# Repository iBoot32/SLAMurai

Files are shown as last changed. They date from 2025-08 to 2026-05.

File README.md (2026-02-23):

SLAM Robot

# SLAMurai Autonomous Robot

This project is an open-source implementation of a SLAM (Simultaneous Localization and Mapping) robot.  
All CAD and software is contained within this repo.

---

## Requirement Check

- [x] Omnidirectional movement using 4 dual-layer omniwheels  
- [x] Report odometry accurate to 3cm at 8ft range  
  - Last test: 12/20/2025 with 0.5% error in forward odom, within 3% error for side movement when moving 8ft straight. And 3cm off-center drift when doing pure diagonal.

---

## Features

- Real-time mapping (SLAM Toolbox)  
- Autonomous navigation (Nav2)  
- High-precision stepper-based odometry  

---

# Detailed Robot Design

## Payload

- 4x NEMA 17 Stepper Motors: 0.25kg each = 1.0kg total  
- 4x 60mm Omni wheels: 0.1kg each = 0.4kg total  
- 1x 6000mAh Lipo battery: 0.55kg  
- 1x NVIDIA Jetson Xavier NX: 0.2kg  
- 1x Intel RealSense D455: 0.3kg  
- 3x Chassis plates: 0.3kg total  
- 1x RPLIDAR A1: 0.2kg  

**Total weight: 3.5kg rounded**

---

## Desired robot specs

- Speed: 0.3 m/s  
- Acceleration: 0.5 m/s²  
- Max payload: 3.5 kg  
- Wheels: 60mm (0.0297m radius) omni wheels in 90° configuration  
- Worst case surface: Concrete (Rolling resistance ~0.03)  
- Torque safety factor: 2  

---

# Selecting Motor Parameters

## Required torque

$$
F_{\text{roll}} = \mu \cdot F_{\text{normal}} = 0.03 \cdot 3.5 \text{kg} \cdot 9.81 \text{m/s}^2 = 1.03 \text{N}
$$

$$
F_{\text{accel}} = 3.5 \text{kg} \cdot 0.5 \text{m/s}^2 = 1.75 \text{N}
$$

$$
F_{\text{total}} = 1.03 \text{N} + 1.75 \text{N} = \boxed{2.78 \text{N}}
$$

$$
\tau = F_{\text{total}} \cdot r_{\text{wheel}} = 2.78 \text{N} \cdot 0.0297 \text{m} = \boxed{0.082 \text{Nm}}
$$

This gives us the total torque required for the robot to meet our acceleration target. However, we need the worst-case torque per motor. One might assume it splits evenly between two motors when moving forward/backward or left/right. But could diagonal movement need more?

<p align="center">
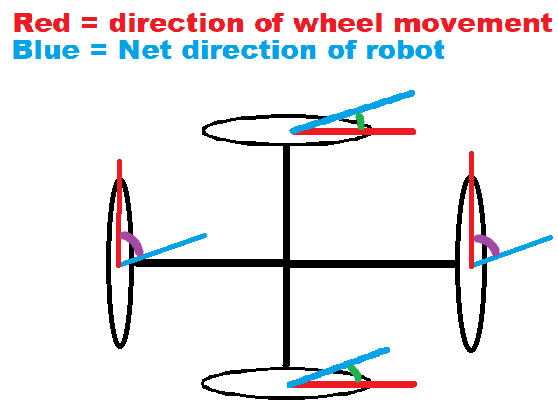
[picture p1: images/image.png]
  
</p>

If each motor provides torque $T$, the top/bottom motors contribute $2T\cos(\theta)$ and left/right motors $2T\cos(90^\circ - \theta)$, where $\theta$ is the angle of travel. We can solve for $T$ to achieve some total torque $\tau$:

$$
\tau = 2T\cos(\theta) + 2T\cos(90^\circ - \theta) \implies
T = \frac{\tau}{2(\cos(\theta) + \sin(\theta))}
$$

$T$ peaks when $\cos(\theta) + \sin(\theta)$ is minimized. We only consider $0 \leq \theta \leq 90^\circ$ since if the angle is $> 90^\circ$, we switch the direction of the top/bottom motors, yielding an angle $0 \leq \theta \leq 90^\circ$ again. Therefore the maximum of $T$ occurs when $\theta = 0^\circ$ or $90^\circ$. So yes, the worst case is moving purely along the top/bottom or left/right axes, splitting torque evenly:

$$
T = \frac{\tau}{2} = \frac{0.082 \text{Nm}}{2} = \boxed{0.041 \text{Nm}} \cdot 2_{\text{(safety factor)}} \approx \boxed{0.082 \text{Nm worst case per motor}}
$$

---

## Required RPM

$$
\text{RPM} = \frac{\text{Target velocity} \cdot 60}{2\pi r}
= \frac{0.3 \text{m/s} \cdot 60}{2\pi \cdot 0.0297 \text{m}}
\approx \boxed{96.5 \text{RPM}}
$$

---

## Motor & Driver Selection

- NEMA 17 Stepper Motors paired with an Arduino CNC Shield  
- 800 steps/rev (1/4 microstepping)  

Driver:

- A4988 or DRV8825 drivers  
- Up to 2A current capability  

Steppers provide high holding torque and precise positioning without needing external encoders. While they don't have current sensing, the open-loop nature of steppers is offset by our odometry integration.

---

# Battery Selection & Longevity

- Voltage: 12V (3S Lipo)  
- Desired Runtime: 1 hour  

## Total continuous current draw

- Motors: 0.4A each → 1.6A total  
- Jetson Xavier NX: ~15W @ 12V → 1.25A  
- RealSense D455: ~3.5W @ 5V → ~0.35A at 12V side  
- RPLIDAR A1: ~100mA  

$$
I_{\text{total}} \approx 1.6 + 1.25 + 0.35 + 0.1 = \boxed{3.3 \text{A}}
$$

To run for 1 hour:

$$
\text{Capacity} = I_{\text{total}} \cdot \text{Time}
= 3.3 \text{A} \cdot 1 \text{h}
= 3.3 \text{Ah}
= 3300 \text{mAh}
$$

Our 6000mAh battery is more than sufficient, providing a significant safety margin.

---

# Wheel Kinematics

We use inverse kinematics to command motor speeds from a target chassis twist and forward kinematics to compute odometry.

## Inverse Kinematics

$$
\begin{aligned}
\begin{bmatrix}
\omega_1\\
\omega_2\\
\omega_3\\
\omega_4
\end{bmatrix}
&=
\frac{1}{r}
\begin{bmatrix}
\sin(\gamma) & -\cos(\gamma) & -R \\
\sin\left(\frac{\pi}{2} + \gamma\right) & -\cos\left(\frac{\pi}{2} + \gamma\right) & -R \\
\sin(\pi + \gamma) & -\cos(\pi + \gamma) & -R \\
\sin\left(\frac{3\pi}{2} + \gamma\right) & -\cos\left(\frac{3\pi}{2} + \gamma\right) & -R
\end{bmatrix}
\begin{bmatrix}
v_{b,x}\\
v_{b,y}\\
\omega_{b,z}
\end{bmatrix}
\end{aligned}
$$

Where:

- $r = 0.0297\text{m}$  
- $R = 0.1325\text{m}$  
- $\gamma = 0$  

Simplified implementation (motor_controller.ino):

```
v_{Front} = -(v_y + R * omega)
v_{Left} = (v_x - R * omega)
v_{Back} = (v_y - R * omega)
v_{Right} = -(v_x + R * omega)
```

---

## Forward Kinematics

$$
\begin{aligned}
\begin{bmatrix}
v_{b,x}\\
v_{b,y}\\
\omega_{b,z}
\end{bmatrix}
&=
\begin{bmatrix}
0 & 0.5 & 0 & -0.5 \\
-0.5 & 0 & 0.5 & 0 \\
-\frac{1}{4R} & -\frac{1}{4R} & -\frac{1}{4R} & -\frac{1}{4R}
\end{bmatrix}
\begin{bmatrix}
\Delta s_1\\
\Delta s_2\\
\Delta s_3\\
\Delta s_4
\end{bmatrix}
\end{aligned}
$$

---

# Software Implementation

## Motor Control (Arduino)

The motor_controller.ino uses the MobaTools library for smooth, ramped stepper control.

- Serial Parsing: Reads $v_x$, $v_y$, $\omega$ at 40Hz  
- Speed Clamping: Ensures steps/sec never exceed STEPS_PER_SEC_MAX (2000 steps/s)  
- Odometry Integration: Calculates and broadcasts $x$, $y$, yaw over serial  

---

## Navigation Bridge (Python/ROS2)

The main.py node handles the Jetson-to-Arduino communication:

- Command Forwarding: Converts ROS Twist messages into serial strings  
- Odometry Publishing: Publishes nav_msgs/Odometry with appropriate covariances  

---

## Autonomous Navigation (Nav2)

Fully integrated with Nav2.

nav2_params.yaml limits:

```
max_vel_x: 0.25 m/s
max_vel_theta: 1.5 rad/s
```

This ensures reliable stepper performance without missing steps during complex maneuvers.

---

# License

MIT License

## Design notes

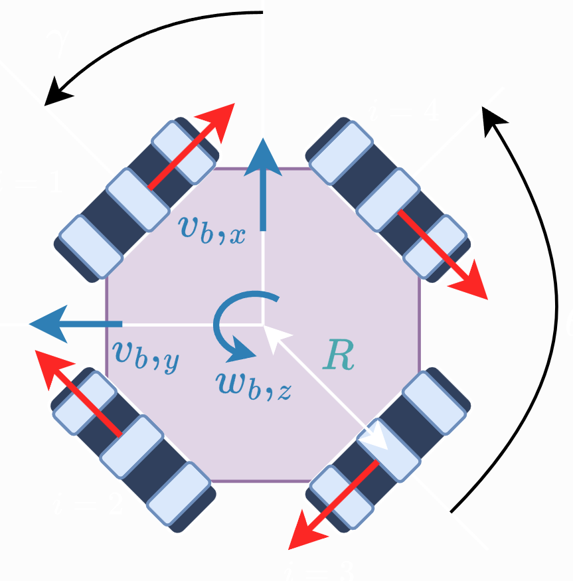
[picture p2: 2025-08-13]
images/robot_frame.PNG

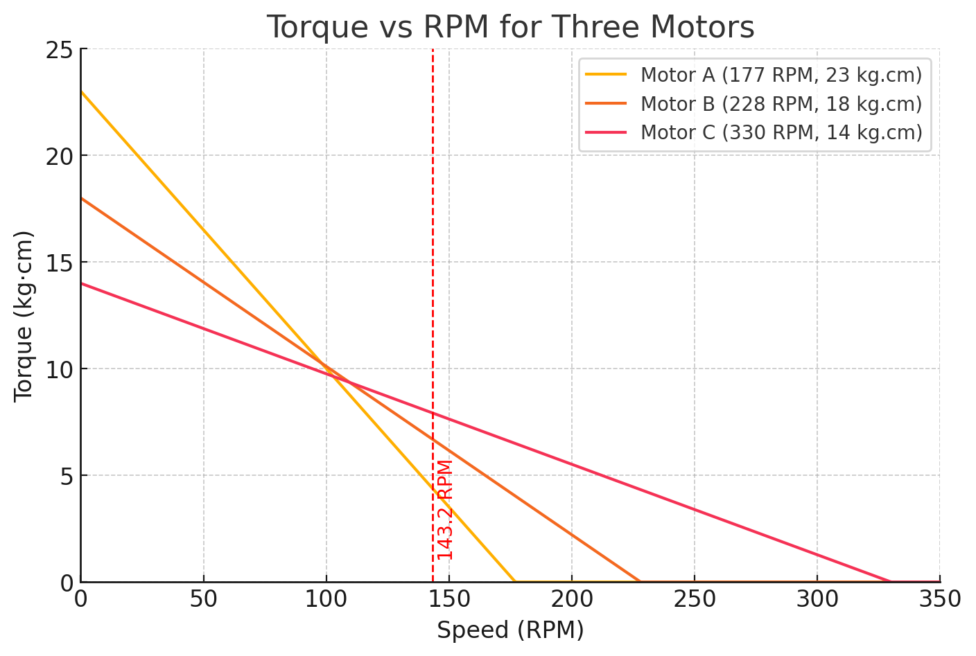
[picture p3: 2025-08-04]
images/torque_rpm.png

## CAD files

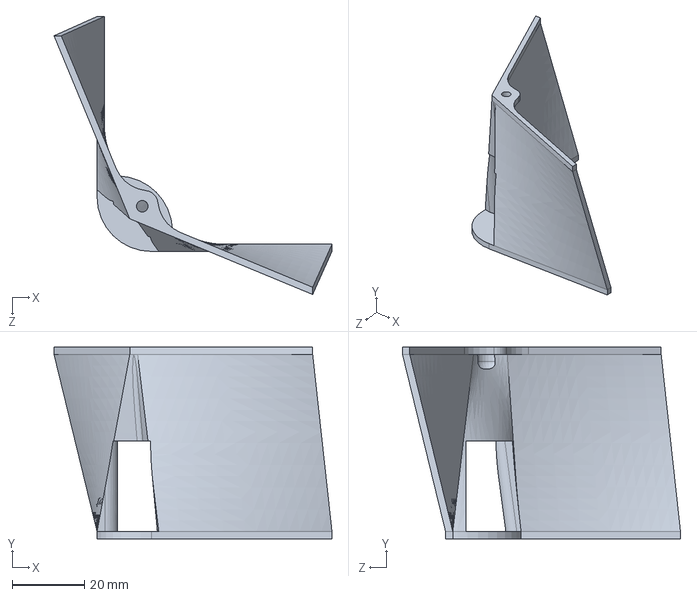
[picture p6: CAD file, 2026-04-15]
robot_cad/chassis_wall.SLDPRT
76.9 x 53.0 x 76.9 mm

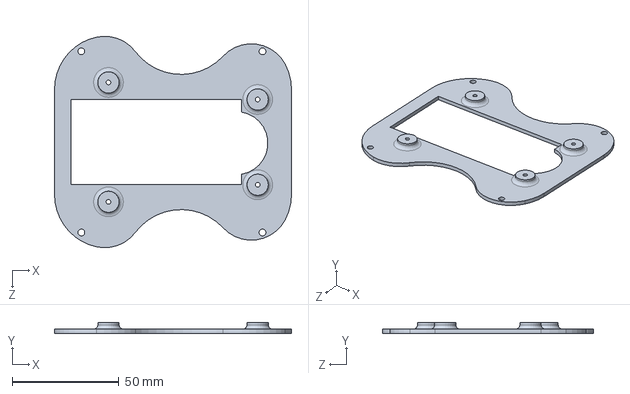
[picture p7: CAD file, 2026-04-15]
robot_cad/lidar_adapter.SLDPRT
111.2 x 5.00 x 99.2 mm

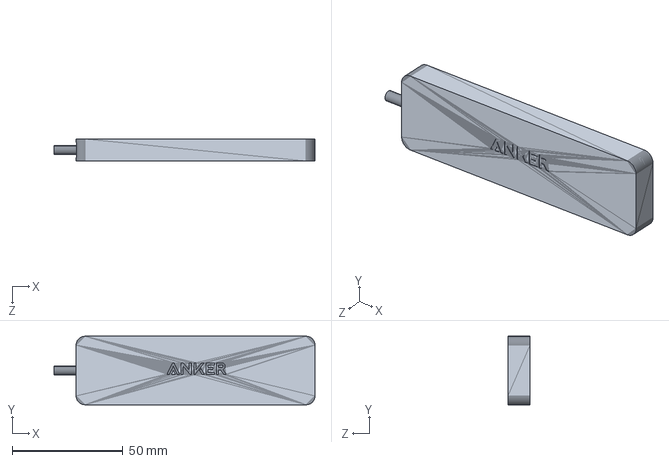
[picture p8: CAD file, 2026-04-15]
robot_cad/4-port usb 3.0 hub.SLDPRT
118.0 x 31.0 x 10.0 mm

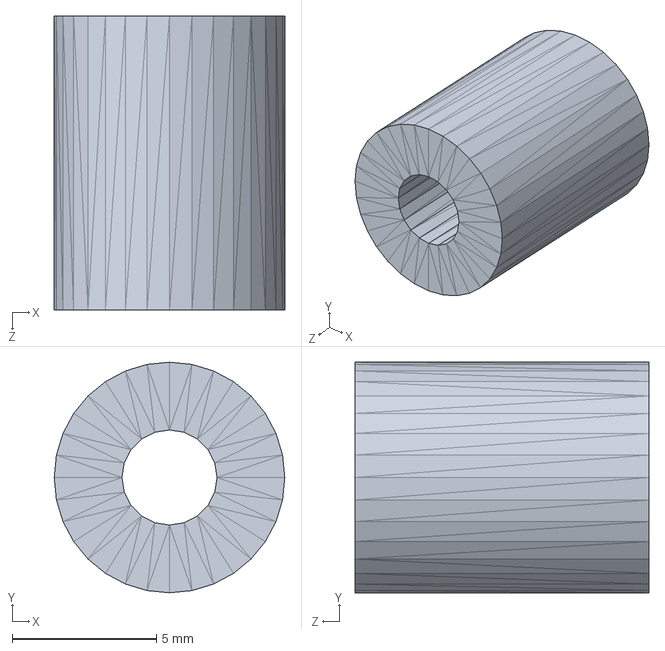
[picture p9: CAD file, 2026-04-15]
robot_cad/omni_spacer.SLDPRT
8.00 x 8.00 x 10.2 mm

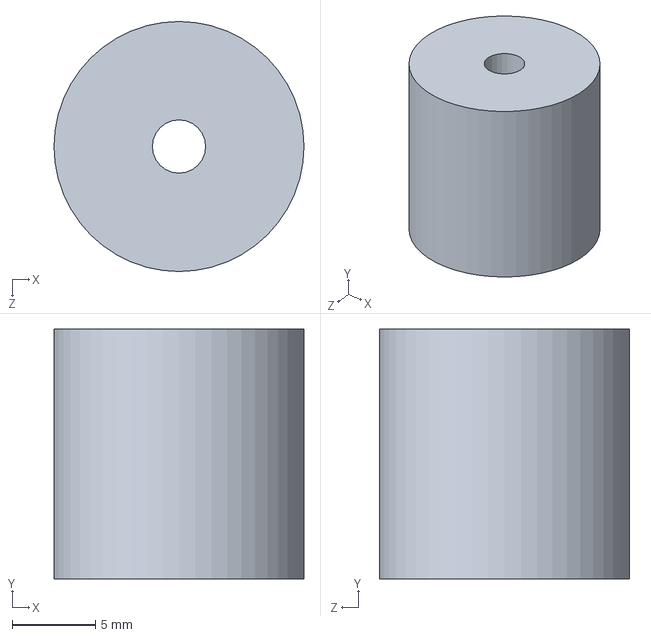
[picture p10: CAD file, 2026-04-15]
robot_cad/standoff_middle.SLDPRT
15.0 x 15.0 x 15.0 mm

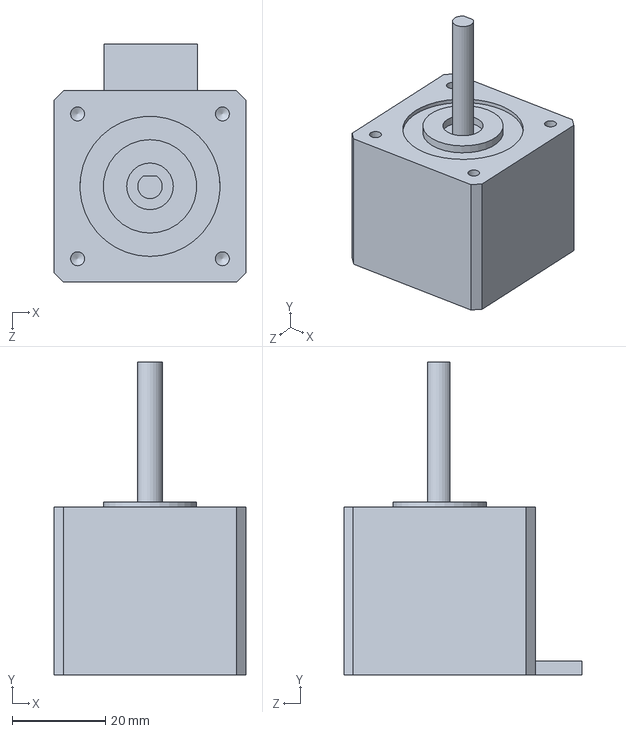
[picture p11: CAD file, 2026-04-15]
robot_cad/Stepper Motor NEMA 17 Smaller Body.SLDPRT
41.0 x 67.0 x 51.0 mm

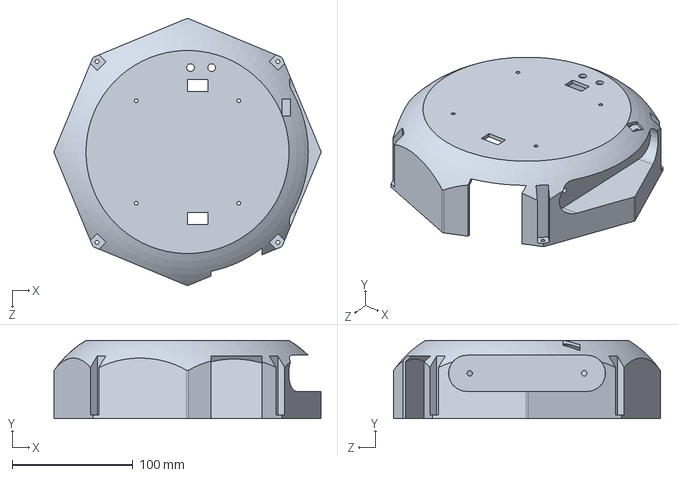
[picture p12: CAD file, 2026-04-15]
robot_cad/topv2.SLDPRT
221.5 x 65.0 x 221.5 mm

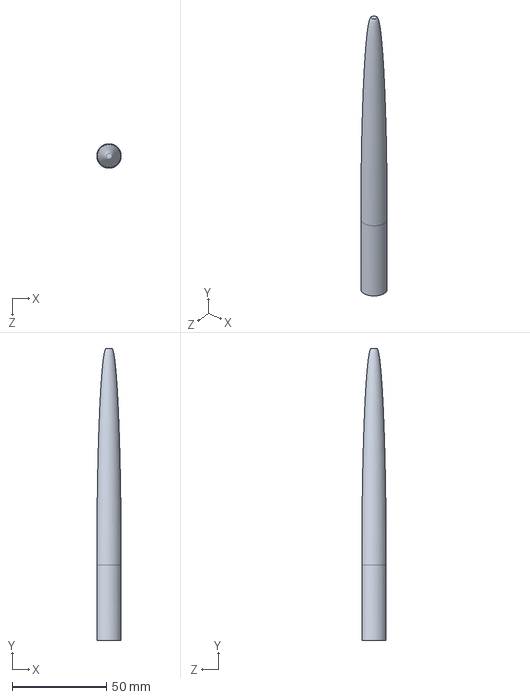
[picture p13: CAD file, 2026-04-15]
robot_cad/antenna.SLDPRT
13.0 x 155.0 x 13.0 mm

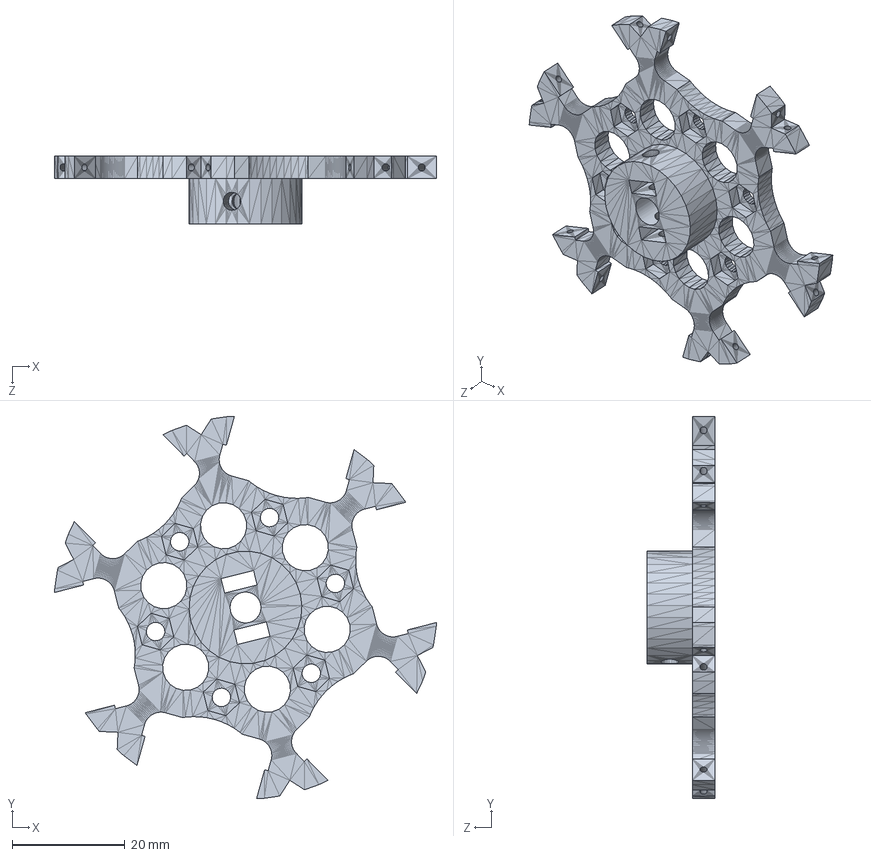
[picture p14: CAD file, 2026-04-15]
robot_cad/wheel_motor_side.SLDPRT
67.7 x 67.8 x 12.0 mm

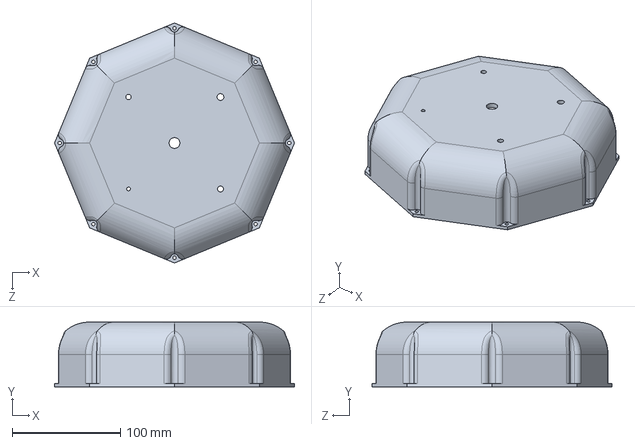
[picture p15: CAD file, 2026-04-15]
robot_cad/robot_top.SLDPRT
221.9 x 60.0 x 221.9 mm

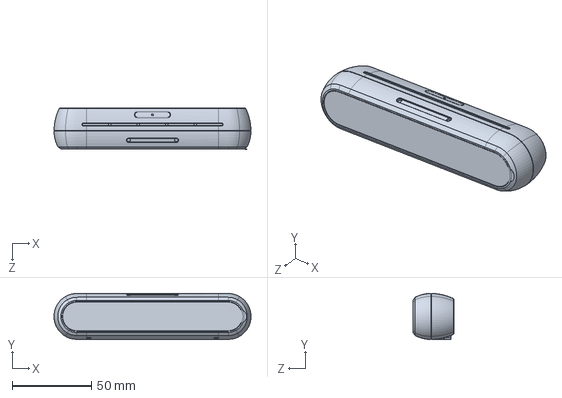
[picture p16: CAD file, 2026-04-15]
robot_cad/D455_Solid.SLDPRT
124.0 x 29.1 x 26.0 mm

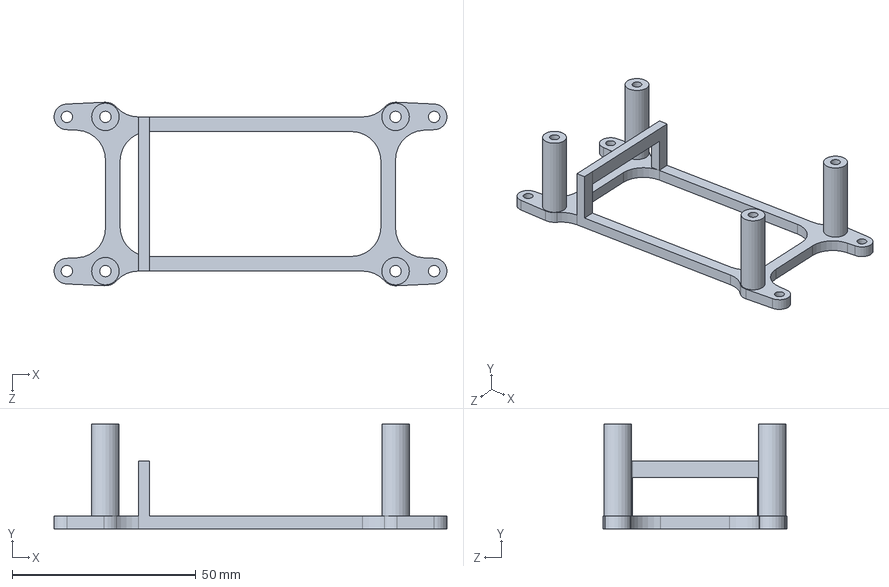
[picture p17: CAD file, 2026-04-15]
robot_cad/tx2bracked.SLDPRT
107.0 x 28.5 x 50.0 mm

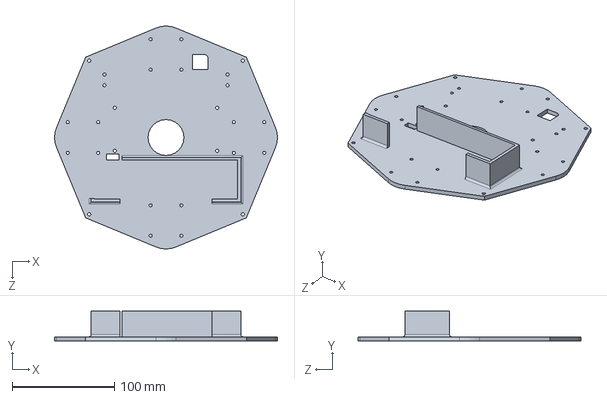
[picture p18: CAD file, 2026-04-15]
robot_cad/middle-plate.SLDPRT
217.8 x 29.0 x 217.8 mm

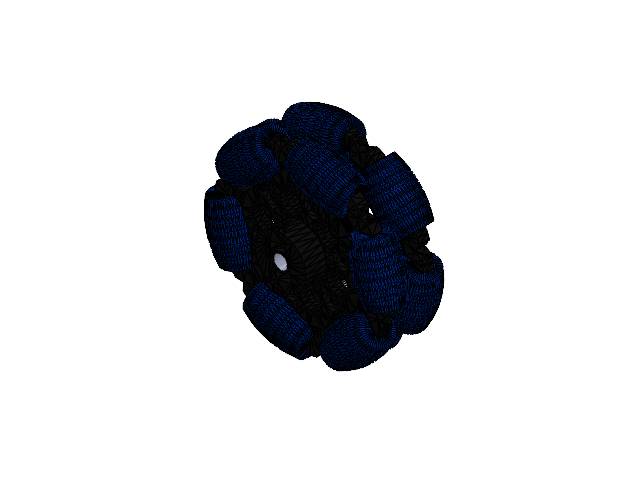
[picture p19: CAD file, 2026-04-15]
robot_cad/wheel_assem.SLDASM
wheel_motor_side
omni_roller x 12
omni_side2
omni_spacer x 3

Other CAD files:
robot_cad/Cable_3-assemv2.SLDASM
robot_cad/Cable_2-assemv2.SLDASM
robot_cad/Cable_1-assemv2.SLDASM
robot_cad/chassis_wall_no_hole.SLDPRT
robot_cad/130817_1-assemv2.SLDASM
robot_cad/ArduinoMega.SLDPRT
robot_cad/Arduino_Uno_CNC_Shield_V3.SLDPRT
robot_cad/NEMA 17 A-Body.step
robot_cad/PLASTIC HEX SPACER M3 L25.SLDPRT
robot_cad/RM_ESC_Center_Board2.stp
robot_cad/Stepper Motor NEMA 17 (1).SLDPRT
robot_cad/battery_11V_5200mAh.SLDPRT
robot_cad/chassis_layer2.SLDPRT
robot_cad/chassis_shell.SLDPRT
robot_cad/chassis_shell_final.SLDPRT
robot_cad/devkit_tx2.SLDPRT
robot_cad/layer1_shell.SLDPRT
robot_cad/middle_plate.SLDPRT
robot_cad/motor_mount.SLDPRT
robot_cad/motor_shaft.SLDPRT
robot_cad/nema_adapter.SLDPRT
robot_cad/omni_roller.SLDPRT
robot_cad/omni_side2.SLDPRT
robot_cad/standoff_53mm.SLDPRT
robot_cad/standoff_53mm.stl

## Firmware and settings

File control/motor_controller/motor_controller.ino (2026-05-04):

#include <MobaTools.h>
#include <math.h>
#define ENABLE_PIN 8
#define DISABLE_ALL_STEPPERS 0

// Robot params
#define WHEEL_RADIUS_M 0.0297
#define ROBOT_CENTER_TO_WHEEL_RADIUS 0.1325
#define STEPS_PER_REV 3200
#define STEPS_PER_SEC_MAX 5000
const float STEPS_PER_M = (float)STEPS_PER_REV / (2.0f * (float)M_PI * WHEEL_RADIUS_M);

// Kinematic Acceleration & Deceleration Limits
#define ACCEL_XY 0.40f // m/s^2
#define DECEL_XY 0.55f // m/s^2 
#define ACCEL_W  2.0f // rad/s^2
#define DECEL_W  2.0f // rad/s^2

// ------- cmd_vel parser --------
bool read_line_float(float* out) {
  static char rxbuf[64];
  static uint8_t rxlen = 0;
  while (Serial.available()) {
    char c = (char)Serial.read();
    if (c == '\n' || c == '\r') {
      if (rxlen == 0) continue;
      rxbuf[rxlen] = '\0'; rxlen = 0;
      char *p = rxbuf;
      for (int i = 0; i < 3; i++) {
        out[i] = (float)strtod(p, &p);
        if (*p == ',') p++;
      }
      return true;
    }
    if (rxlen + 1 < sizeof(rxbuf)) rxbuf[rxlen++] = c;
  }
  return false;
}

// --------- Stepper wrapper ----------
struct Stepper {
  MoToStepper drv;
  uint8_t _stepPin, _dirPin;
  Stepper(uint8_t step, uint8_t dir) : drv(STEPS_PER_REV, STEPDIR), _stepPin(step), _dirPin(dir) {}
  inline long pos() const { return drv.readSteps(); }

  void setup() { 
    drv.attach(_stepPin, _dirPin); 
    drv.setRampLen(0);
    drv.setSpeed(0);
  }

  void setLinearVelocity(float v_mps) {
    float sps = v_mps * STEPS_PER_M;
    if (fabs(sps) > STEPS_PER_SEC_MAX) sps = copysign(STEPS_PER_SEC_MAX, sps);
    if (fabs(sps) < 1e-3) {
      drv.rotate(0);
      drv.setSpeedSteps(0);
      return;
    }
    uint16_t steps10 = (uint16_t)(fabs(sps) * 10.0f);    drv.setSpeedSteps(steps10);
    if (sps == 0) {
      drv.setSpeedSteps(0);
    } else if (sps > 0) {
      drv.rotate(1);
    } else {
      drv.rotate(-1);
    }
  }
};

Stepper stepperFront(3, 6);
Stepper stepperLeft(2, 5);
Stepper stepperBack(4, 7);
Stepper stepperRight(12, 13);

void setup() {
  Serial.begin(115200);
  pinMode(ENABLE_PIN, OUTPUT);
  if (DISABLE_ALL_STEPPERS) { digitalWrite(ENABLE_PIN, HIGH); return; }
  digitalWrite(ENABLE_PIN, LOW);
  delayMicroseconds(2000);
  stepperFront.setup(); stepperLeft.setup(); stepperBack.setup(); stepperRight.setup();
}

// -------- KINEMATIC STATE --------
float target_vx = 0, target_vy = 0, target_w = 0;
float current_vx = 0, current_vy = 0, current_w = 0;

float CMD_VEL_READ_PERIOD_US = 1e6 * (1 / 40.0);
unsigned long last_cmd_vel_send_time = 0;
unsigned long last_cmd_received_time = 0;
const unsigned long CMD_TIMEOUT_US = 500000;

float ODOM_SEND_PERIOD_US = 1e6 * (1 / 40.0);
float pose_x = 0, pose_y = 0, pose_yaw = 0;
float dx_b_sum = 0, dy_b_sum = 0, dyaw_sum = 0; 
long lastFront = 0, lastLeft = 0, lastBack = 0, lastRight = 0;
unsigned long last_odom_send_time = 0;

float move_towards(float current, float target, float accel_limit, float decel_limit, float dt) {
  if (current == target) return current;
  bool accelerating = (target > 0 && current >= 0 && target > current) || (target < 0 && current <= 0 && target < current);
  float max_step = (accelerating ? accel_limit : decel_limit) * dt;
  if (current < target) {
    current += max_step;
    if (current > target) current = target;
  } else {
    current -= max_step;
    if (current < target) current = target;
  }
  return current;
}

void loop() {
  unsigned long now = micros();
  float cmd_v[3];
  if (read_line_float(cmd_v)) {
    
    last_cmd_received_time = now;
    target_vx = cmd_v[0];
    target_vy = cmd_v[1];
    target_w  = cmd_v[2];
  }

  // ---- KINEMATIC TIMING & SMOOTHING ----
  if (now - last_cmd_vel_send_time >= CMD_VEL_READ_PERIOD_US) {
    float dt_smooth = (now - last_cmd_vel_send_time) / 1000000.0f;
    last_cmd_vel_send_time = now;

    // Timeout Safety
    if (now - last_cmd_received_time > CMD_TIMEOUT_US) {
      target_vx = 0; target_vy = 0; target_w = 0;
    }

    // Apply acceleration limits
    current_vx = move_towards(current_vx, target_vx, ACCEL_XY, DECEL_XY, dt_smooth);
    current_vy = move_towards(current_vy, target_vy, ACCEL_XY, DECEL_XY, dt_smooth);
    current_w  = move_towards(current_w,  target_w,  ACCEL_W,  DECEL_W,  dt_smooth);

    float vFront = -(current_vy + ROBOT_CENTER_TO_WHEEL_RADIUS * current_w);
    float vLeft  =  (current_vx - ROBOT_CENTER_TO_WHEEL_RADIUS * current_w);
    float vBack  =  (current_vy - ROBOT_CENTER_TO_WHEEL_RADIUS * current_w);
    float vRight = -(current_vx + ROBOT_CENTER_TO_WHEEL_RADIUS * current_w);
   
    stepperFront.setLinearVelocity(vFront);
    stepperLeft.setLinearVelocity(vLeft);
    stepperBack.setLinearVelocity(vBack);
    stepperRight.setLinearVelocity(vRight);
  }

  // ---- ODOM UPDATE (Runs as fast as possible) ----
  long pFront = stepperFront.pos();
  long pLeft = stepperLeft.pos();
  long pBack = stepperBack.pos();
  long pRight = stepperRight.pos();

  long dFront = pFront - lastFront;
  long dLeft = pLeft - lastLeft;
  long dBack = pBack - lastBack;
  long dRight = pRight - lastRight;
  lastFront = pFront; lastLeft = pLeft; lastBack = pBack; lastRight = pRight;

  float sFront = (float)dFront / STEPS_PER_M;
  float sLeft = (float)dLeft / STEPS_PER_M;
  float sBack = (float)dBack / STEPS_PER_M;
  float sRight = (float)dRight / STEPS_PER_M;

  float dx_b = ( sLeft - sRight ) * 0.5f;
  float dy_b = (-sFront + sBack ) * 0.5f;
  float dyaw = -(sFront + sLeft + sBack + sRight) * (1.0f / (4.0f * ROBOT_CENTER_TO_WHEEL_RADIUS));

  dx_b_sum += dx_b;
  dy_b_sum += dy_b;
  dyaw_sum += dyaw;

  float cy = cos(pose_yaw);
  float sy = sin(pose_yaw);
  pose_x += cy * dx_b - sy * dy_b;
  pose_y += sy * dx_b + cy * dy_b;
  pose_yaw += dyaw;

  // ---- SERIAL ODOM SEND ----
  now = micros();
  if (now - last_odom_send_time >= ODOM_SEND_PERIOD_US) {
    float dt_odom = (now - last_odom_send_time) / 1000000.0f;
    last_odom_send_time = now;

    float x_mm = roundf(pose_x * 1000.0f) / 1000.0f;
    float y_mm = roundf(pose_y * 1000.0f) / 1000.0f;
    float yaw_r = roundf(pose_yaw * 1000.0f) / 1000.0f;
    float vel_x = dx_b_sum / dt_odom;
    float vel_y = dy_b_sum / dt_odom;
    float vel_w = dyaw_sum / dt_odom;

    dx_b_sum = 0; dy_b_sum = 0; dyaw_sum = 0;

    Serial.print(x_mm, 3); Serial.print(',');
    Serial.print(y_mm, 3); Serial.print(',');
    Serial.print(yaw_r, 3); Serial.print(',');
    Serial.print(vel_x, 3); Serial.print(',');
    Serial.print(vel_y, 3); Serial.print(',');
    Serial.println(vel_w, 3);
  }
}

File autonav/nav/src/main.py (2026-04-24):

#!/usr/bin/env python3
import rclpy
from rclpy.node import Node
from rclpy.qos import QoSProfile, QoSReliabilityPolicy
from nav_msgs.msg import Odometry
from geometry_msgs.msg import Twist
import serial
import time
import math


class CmdVelSerialOdom(Node):
    def __init__(self, ser, hz=50.0):
        super().__init__('cmdvel_serial_odom')
        self.ser = ser

        qos = QoSProfile(depth=10)
        qos.reliability = QoSReliabilityPolicy.BEST_EFFORT

        self.publisher = self.create_publisher(Odometry, '/odometry/raw', 10)
        self.subscriber = self.create_subscription(
            Twist, '/cmd_vel', self.cmd_vel_callback, qos)

        self.frame_id = "odom"
        self.child_frame_id = "base_link"

        # Current odom pose
        self.x = 0.0
        self.y = 0.0
        self.yaw = 0.0
        
        # Current odom velocity
        self.vx = 0.0
        self.vy = 0.0
        self.vw = 0.0

        self.create_timer(1.0 / hz, self.publish_odom)

    # Writes data via USB serial to be received by Arduino
    def cmd_vel_callback(self, msg: Twist):
        cmd = f"{msg.linear.x},{msg.linear.y},{msg.angular.z}\n"
        self.ser.write(cmd.encode())

    def publish_odom(self):
        # Read any available odom serial line from Arduino
        try:
            line = self.ser.readline().decode().strip()
            if line:
                parts = line.split(',')
                if len(parts) == 6:
                    self.x = float(parts[0])   # meters
                    self.y = float(parts[1])
                    self.yaw = float(parts[2])
                    self.vx = float(parts[3])  # meters/sec
                    self.vy = float(parts[4])
                    self.vw = float(parts[5])
        except Exception:
            pass  # ignore malformed lines

        # Convert yaw -> quaternion
        qz = math.sin(self.yaw * 0.5)
        qw = math.cos(self.yaw * 0.5)

        msg = Odometry()
        msg.header.stamp = self.get_clock().now().to_msg()
        msg.header.frame_id = self.frame_id
        msg.child_frame_id = self.child_frame_id

        # Populate Pose
        msg.pose.pose.position.x = self.x
        msg.pose.pose.position.y = self.y
        msg.pose.pose.position.z = 0.0
        msg.pose.pose.orientation.x = 0.0
        msg.pose.pose.orientation.y = 0.0
        msg.pose.pose.orientation.z = qz
        msg.pose.pose.orientation.w = qw
        
        # 5mm std in pose, 0.1deg std orientation
        msg.pose.covariance = [
            2.5e-05, 0.0,     0.0,     0.0,     0.0,     0.0,
            0.0,     2.5e-05, 0.0,     0.0,     0.0,     0.0,
            0.0,     0.0,     1.0,     0.0,     0.0,     0.0,
            0.0,     0.0,     0.0,     1.0,     0.0,     0.0,
            0.0,     0.0,     0.0,     0.0,     1.0,     0.0,
            0.0,     0.0,     0.0,     0.0,     0.0,     3.05e-06
        ]

        # Populate Twist (Velocity)
        msg.twist.twist.linear.x = self.vx
        msg.twist.twist.linear.y = self.vy
        msg.twist.twist.linear.z = 0.0
        msg.twist.twist.angular.x = 0.0
        msg.twist.twist.angular.y = 0.0
        msg.twist.twist.angular.z = self.vw
        
        # Basic twist covariance 
        msg.twist.covariance = [
            1e-4, 0.0,  0.0,  0.0,  0.0,  0.0,
            0.0,  1e-4, 0.0,  0.0,  0.0,  0.0,
            0.0,  0.0,  1e-4, 0.0,  0.0,  0.0,
            0.0,  0.0,  0.0,  1e-4, 0.0,  0.0,
            0.0,  0.0,  0.0,  0.0,  1e-4, 0.0,
            0.0,  0.0,  0.0,  0.0,  0.0,  1e-4
        ]

        self.publisher.publish(msg)

def main():
    rclpy.init()

    port = '/dev/ttyACM0'
    baud = 115200
    hz = 50.0

    ser = serial.Serial(port=port, baudrate=baud, timeout=0.01)

    time.sleep(3)
    ser.reset_input_buffer()

    node = CmdVelSerialOdom(ser, hz)

    try:
        rclpy.spin(node)
    except KeyboardInterrupt:
        pass
    finally:
        node.destroy_node()
        rclpy.shutdown()
        ser.close()

if __name__ == '__main__':
    main()

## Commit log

2025-07-26 add basic asserts, now uses Madgwick Filter to compute orientation from IMU and converts depthmap to a laserscan
2025-07-29 add robot cad WIP
    [Aslong 37mm Diameter 12V 333RPM.SLDPRT, D455_Solid.SLDPRT, PLASTIC HEX SPACER M3 L25.SLDPRT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]
2025-08-03 compute torque and rpm, add more sldprt
    [Motor Driver.SLDPRT, battery_14.8V_600mAh.SLDPRT, tx2_devkit.SLDPRT]
2025-08-04 add torque and current juistification
2025-08-04 finish battery calculations
2025-08-09 update motor controller to accept cmd_vel as a decimal over serial, add barebones script to send/read cmd_vel/odom from TX2
    [battery_11V_5200mAh.SLDPRT, battery_14.8V_600mAh.SLDPRT, chassis_layer2.SLDPRT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]
2025-08-13 update readme for kinematics, update motor control script for setting velocity of 4 motors over serial
2025-08-13 add inverse kinematics for each motor
2025-08-13 increase baud and drop other services for now. due to serial printing we have inconsistent pulses which leads to drift. TODO: fix
    [motor_controller.ino]
2025-08-23 validate max vx and vy and w params for nav2
    [ArduinoMega.SLDPRT, Arduino_Uno_CNC_Shield_V3.SLDPRT, NEMA 17 A-Body.step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]
2025-08-27 add layout for nav2 params and bringup launch. also basic urdf for chassis+realsense
2025-08-29 add urdf, robot_localization imu+odom fuse, and basic bringup launch
2025-09-01 resolve IMU drift via accounting for steady-state bias, also estimate initial orientation from steady-state linear acc to improve EKF convergence
    [_d415.urdf.xacro, _d435.urdf.xacro, _d435i.urdf.xacro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]
2025-09-01 add more sensor tfs
2025-09-03 fix baselink and odom urdf bug, add basic working slam_toolbox
2025-09-05 fix ekf fusing rot vel, keep vx,vy,vz. move main rs exec to be python file, prep for pose scheduler
    [main.py]
2025-09-07 increase depth power, change to base_link from base_footprint for scan rotation fix, update main.py to take /cmd_vel and write to serial.
    [main.py]
2025-09-07 remove odom read, odom now computed from cmd_vel under assumption of no slip. double map publish rate
    [main.py]
2025-11-12 adjust lidar placement, enable scan matching
2025-11-19 comment the URDF. remove odom from urdf. update lidar position.
2025-11-21 update EKF frequency and base link frame; adjust gyro and accel FPS
2025-11-21 update frames, set gyro+accel hz, add imu to odom
2025-11-22 update EKF configuration, adjust map update interval, and refine motor controller parameters
2025-11-22 update urdf to match real robot and add wheels purely for visual
2025-11-24 fix urdf coloring and remove wheels
2025-11-24 change madgwick frame to lidar_link
2025-11-24 fix madgwick to use lidar frame and correct imu axes to match ROS2 convention
2025-12-01 work on sending odom from forward kinematic on arduino instead of using cmd_vel as odom
2025-12-13 adjust wheel radius to match real odom reporting, and change both odom send and cmd_vel to be 2*controller_freq
2025-12-14 update realsense profile, no more scan matching, update URDF measurements, and polish controller layout and params
2025-12-14 add slight accel to smooth velocity commands
2025-12-14 add light acceleration to smooth velocity updates, also support decelerating to zero instead of hard stop
2025-12-14 fix imu covariance, fuse vyaw and linear accel, add odom covariance, and increase steps/sec limit to 2000 per motor
    [main.py, motor_controller.ino]
2025-12-15 disable auto exposure to fix terrible resolution scans, polish filters, add optical frame
2025-12-15 increase to 5.5m range, scan unfinished basement and kitchen for samples
2025-12-17 fix ekf to outputting base_footprint (fixes unconnected tree links which breaks nav2), fix pgm naming inside map yaml, and update nav2 params for my lidar and plugins
2025-12-20 add full map, remove imu for better odom accuracy, trust odom way more and nav2 tunings for performance
2025-12-21 add new map scan, update wheel radius to meet requiremnt, tune nav params for robustness
2026-01-15 update motor controller with semi accurate new wheel params (need to tune), sdk to maybe fix off by 1 scan size, try re-enable scan match. change urdf to have lidar on top, add rplidar sdk
    [motor_controller.ino]
2026-01-16 disable scan matching for calibration, fix lidar size, and adjust wheel radius and robot diameter cals
    [motor_controller.ino]
2026-01-16 increase laser range. need to debug expected vs actual scans mismatch causing scan drop I suspect
2026-01-18 fix scan size issue, tuning robot params but needs more work
    [motor_controller.ino]
2026-02-23 re-organize and polish up codebase
    [_d415.urdf.xacro, _d435.urdf.xacro, _d435i.urdf.xacro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]
2026-02-23 optimize velocities, tune critics to follow global path better
2026-03-01 param improvements, issue where after reaches goal still drives?
    [motor_controller.ino]
2026-03-15 fix bt, now will replan once per second, retry 5x before clearing costmap, then retry infinite times. enable beamskip, fix velociies and thresholds, and tune inflation radius. Now seems to be very cl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
    [motor_controller.ino]
2026-04-10 CAD updates, add cortex for VLM processing of environment
    [130817_1-assemv2.SLDASM, 4-port usb 3.0 hub.SLDPRT, ArduinoMega.SLDPRT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]
2026-04-10 enable chatting with model about stm/ltm/current views, move most prompt logic out of sys prompt
2026-04-12 remove old CAD and realsense CAD to lower file size
    [Aslong 37mm Diameter 12V 333RPM.SLDPRT, Motor Driver.SLDPRT, NEMA 17 A-Body.step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]
2026-04-12 remove old asm
    [Aslong 37mm Diameter 12V 333RPM.SLDPRT, Motor Driver.SLDPRT, NEMA 17 A-Body.step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]
2026-04-12 remove old cad
    [Aslong 37mm Diameter 12V 333RPM.SLDPRT, Motor Driver.SLDPRT, NEMA 17 A-Body.step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]
2026-04-24 implement smoothing on controller side, a crucial fix to allow ramp up and reduce jumpiness when cmd_vel changes quickly. compute velocity on arduino and send for better feedback to nav2
    [main.py, motor_controller.ino]
2026-04-27 more generous accel, read serial more quickly to lower read time, decrease goal tolerance
    [motor_controller.ino]
2026-05-01 remove large meshes
    [d455.stl, plug.stl, plug_collision.stl]
2026-10-12 cmdvel_gui: topic pickers and optional camera view (compressed by default)
2026-10-12 Sync robot-only edits: TMC2209 motor_controller (1600 steps, direction sign, timed odom), f1t map in launch, realsense description CMake
2026-10-12 README: animated v17 assembly gif and rendered robot replace the old photo
2026-10-12 Safety config for the assemv2 robot (plus layout, R 0.1325, URDF lidar); v17 profile kept as *.v17.*; wheel azimuths now come from robot_profile
2026-10-18 assemv2: no lidar blind wedges; safety config regenerated (new lock, needs approval)
2026-10-18 zone editor: view rotation (default x up like RViz top-down), Rotate view button, remembered
2026-10-18 Clearance from the zone editor also sets the stop distance to lidar objects
2026-10-18 Fix gate ramp reset (GUI zero stream on /cmd_vel), telemetry batcher for rosbridge's 10 msg/s limit, revert cmd_stale_s to 0.4
    The cmdvel GUI published zeros at 20 Hz while idle, so the gate saw Nav2's command and a zero in turn and restarted its
    acceleration ramp every step. It now publishes only while driving. Dashing rosbridge spins once per 100 ms, so each
    API stream arrived at ~2 Hz; robot_side/tools/telemetry.py batches 20 Hz samples into one topic.
2026-10-18 main.py: fix serial deadlock (drain Arduino output, write timeout) that froze /odometry/raw
    main read one line per tick and then blocked in write; once the Arduino output backed up (3.7 kB unread) the Arduino blocked
    on Serial.print, stopped reading commands, and neither side could recover.
2026-10-18 gate: publish lidar sectors in every status message
2026-10-18 EKF: fuse wheel pose only, absolute; slam_toolbox: base_footprint, finer travel, loop closure; add imu_check tool
2026-10-18 imu_check: old numpy has no diff prepend
2026-10-18 scan_launch: start color camera; scan.rviz: camera image (compressed hint)
2026-10-18 scan: flip camera image 180, stricter loop closure thresholds
2026-10-18 Remove camera_flip node; camera panel reads raw image
2026-10-18 Add simple camera_flip node (180 deg) for scan launch
2026-10-18 scan.rviz: frame rate 10
2026-10-19 run_route: pause between legs, Nav2 drops a goal sent right after a finished one
2026-10-19 Robot.close: unsubscribe and unadvertise before closing the socket, also at exit
